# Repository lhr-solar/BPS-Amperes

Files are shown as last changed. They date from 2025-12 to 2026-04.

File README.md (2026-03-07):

# BPS-Amperes

### Board Specification
- Measures battery current using low-side shunt resistor.

### Confluence
- https://cloud.wikis.utexas.edu/wiki/spaces/LHRSOLAR/pages/172360934/Amperes+Board

### Building / Testing
- To build main firmware, cd into Firmware folder and run ``` make ``` to build main files. 
- To build tests, cd into Fimrware folder and run ``` make TEST=test_name ```, where ```test_name``` is the name of the test without the .c suffix.
- Run ``` make help ``` for specific instructions.

### Flashing
- Attach USB device using USBIPD and flash via UART (``` make flash-uart ```) or ST-Link (``` make flash ```).

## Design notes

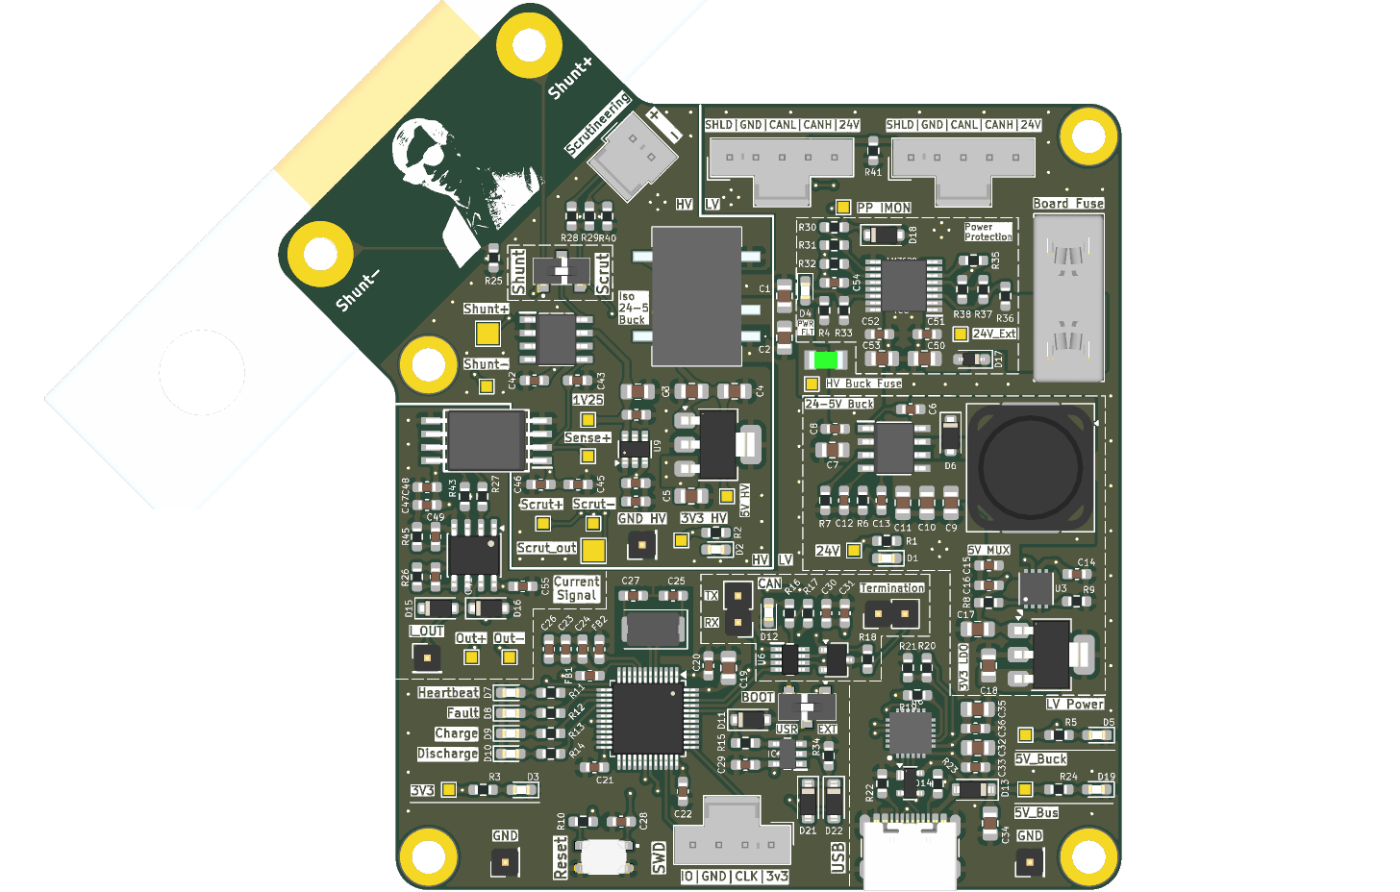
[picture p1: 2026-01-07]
Hardware/docs/render.png

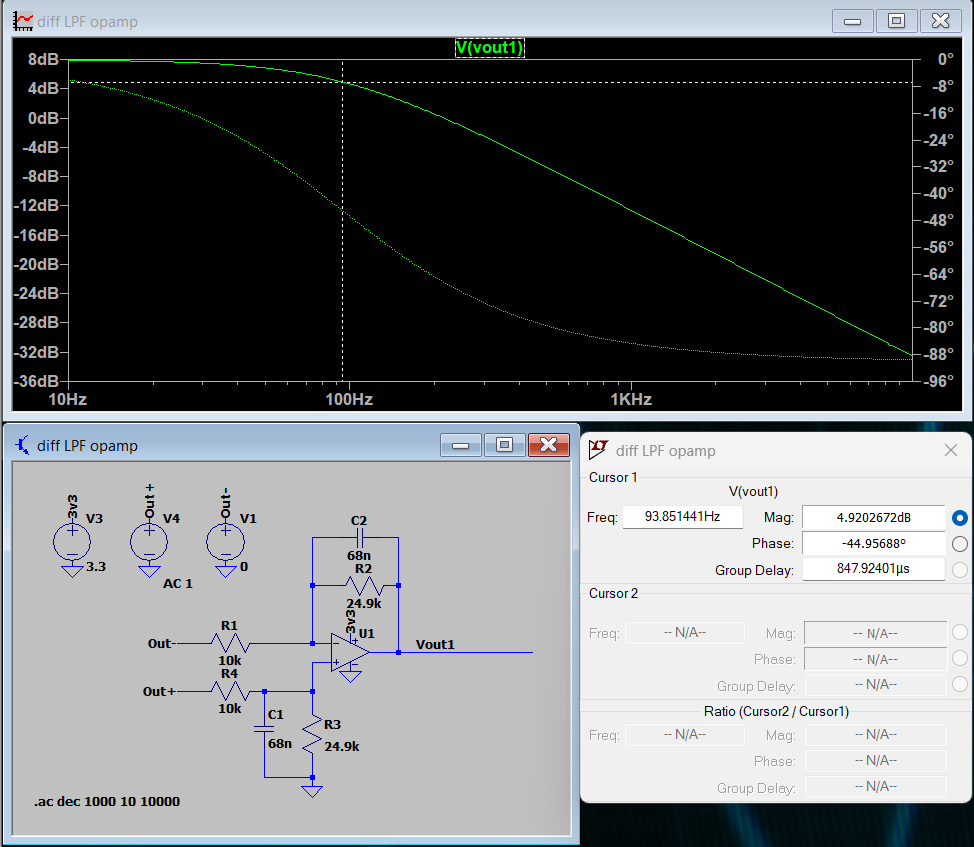
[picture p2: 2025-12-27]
Hardware/Amperes Design/RevB Low-Pass Filter.png

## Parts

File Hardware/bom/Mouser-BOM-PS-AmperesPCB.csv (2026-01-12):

Comment | Mouser P/N | Quantity | Designator
PTC Fuse | 576-1206L010/30WR | 1 | F1
3568 Fuse | 534-3568 | 1 | F2
INA241A4IDR | 595-INA241A4IDR | 1 | IC2
100uH | 994-MSS1246-104MLC | 1 | L1
WE 1769205341 | 710-1769205341 | 1 | PS1
SPDT Switch | 229-CJS-1200TA | 2 | SW2
CDSOT23-T24CAN | 652-CDSOT23-T24CAN | 1 | U7
4.3k 0603 Resistor | 71-CRCW0603-4.3K-E3 | 2 | R1,R4
WSBS8518L2500JTP3 | 71-WSBS8518L2500JTP3 | 1 | R39

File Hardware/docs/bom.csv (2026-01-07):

Reference | Value | Footprint | Qty | p/n
C1,C2,C19,C32,C35 | 4.7uF | Capacitor_SMD:C_0805_2012Metric_Pad1.18x1.45mm_HandSolder | 5
C3,C4,C5,C7,C9,C10,C11,C17,C18,C34,C39,C50,C53 | 10uF | Capacitor_SMD:C_0805_2012Metric_Pad1.18x1.45mm_HandSolder | 13
C6,C14,C15,C29,C33,C36,C37,C40,C42,C55 | 0.1uF | Capacitor_SMD:C_0603_1608Metric_Pad1.08x0.95mm_HandSolder | 10
C8,C16,C38,C46,C47,C51,C52 | 1uF | Capacitor_SMD:C_0603_1608Metric_Pad1.08x0.95mm_HandSolder | 7
C12 | 10nF | Capacitor_SMD:C_0603_1608Metric_Pad1.08x0.95mm_HandSolder | 1
C13 | 3.3nF | Capacitor_SMD:C_0603_1608Metric_Pad1.08x0.95mm_HandSolder | 1
C20,C21,C22,C23,C24,C26,C28,C30,C31,C45,C48,C54 | 100nF | Capacitor_SMD:C_0603_1608Metric_Pad1.08x0.95mm_HandSolder | 12
C25,C27 | 12p | Capacitor_SMD:C_0603_1608Metric_Pad1.08x0.95mm_HandSolder | 2
C41,C49 | 68nF | Capacitor_SMD:C_0603_1608Metric_Pad1.08x0.95mm_HandSolder | 2
C43 | 1nF | Capacitor_SMD:C_0603_1608Metric_Pad1.08x0.95mm_HandSolder | 1
D1,TP3 | 24V | LED_SMD:LED_0603_1608Metric_Pad1.05x0.95mm_HandSolder,TestPoint:TestPoint_Pad_1.0x1.0mm | 2
D2 | 3.3V HV | LED_SMD:LED_0603_1608Metric_Pad1.05x0.95mm_HandSolder | 1
D3 | 3.3V | LED_SMD:LED_0603_1608Metric_Pad1.05x0.95mm_HandSolder | 1
D4 | PFLT | LED_SMD:LED_0603_1608Metric_Pad1.05x0.95mm_HandSolder | 1
D5 | BUCK | LED_SMD:LED_0603_1608Metric_Pad1.05x0.95mm_HandSolder | 1
D6 | MBR230S1F | Diode_SMD:D_SOD-123F | 1
D7 | Heartbeat | LED_SMD:LED_0603_1608Metric_Pad1.05x0.95mm_HandSolder | 1
D8 | Fault | LED_SMD:LED_0603_1608Metric_Pad1.05x0.95mm_HandSolder | 1
D9 | Charge | LED_SMD:LED_0603_1608Metric_Pad1.05x0.95mm_HandSolder | 1
D10 | Discharge | LED_SMD:LED_0603_1608Metric_Pad1.05x0.95mm_HandSolder | 1
D11,D15,D16,D17,D18 | TVS | Diode_SMD:D_SOD-123F,Diode_SMD:D_SOD-323_HandSoldering | 5
D12 | CAN Status | LED_SMD:LED_0603_1608Metric_Pad1.05x0.95mm_HandSolder | 1
D13,D21,D22 | 1N5819HW | Diode_SMD:D_SOD-123 | 3
D14 | SP0503BAHT | Package_TO_SOT_SMD:SOT-143 | 1
D19 | VBUS | LED_SMD:LED_0603_1608Metric_Pad1.05x0.95mm_HandSolder | 1
F1 | Fuse | Parts:FUSC3216X125N | 1
F2 | 3568 | Parts:FUSE_3568 | 1
FB1,FB2 | FerriteBead | Capacitor_SMD:C_0603_1608Metric_Pad1.08x0.95mm_HandSolder | 2
H1 | M1 | MountingHole:MountingHole_3.2mm_M3_DIN965_Pad_TopBottom | 1
H2 | M3 | MountingHole:MountingHole_3.2mm_M3_DIN965_Pad_TopBottom | 1
H3 | M2 | MountingHole:MountingHole_3.2mm_M3_DIN965_Pad_TopBottom | 1
H4 | M4 | MountingHole:MountingHole_3.2mm_M3_DIN965_Pad_TopBottom | 1
IC1 | SN74AHC1G32DBVR | Parts:SN74AHC1G32DBVR | 1
IC2 | INA241A4IDR | Parts:INA241A5IDR | 1
IC3 | AMC1350DWVR | Parts:AMC1350DWVR | 1
IC5 | LM76202QPWPRQ1 | UTSVT_Power:LM76202QPWPRQ1 | 1
J1 | PeripheralCAN | UTSVT_Connectors:Molex_Nano-Fit_105309-xx04_1x04_P2.50mm_Vertical | 1
J3 | SWD | Connector_Molex:Molex_Nano-Fit_105309-xx04_1x04_P2.50mm_Vertical | 1
J4 | Conn_01x02_Pin | Connector_PinHeader_2.54mm:PinHeader_1x02_P2.54mm_Vertical | 1
J5 | USB4105-GF-A | UTSVT_Connectors:USB_C_Receptacle_GCT_USB4105-xx-A_16P_TopMnt_Horizontal | 1
J6 | Scrut Conn | Connector_Molex:Molex_Nano-Fit_105309-xx02_1x02_P2.50mm_Vertical | 1
J7,J8 | Nanofit 1x05 | Connector_Molex:Molex_Nano-Fit_105309-xx05_1x05_P2.50mm_Vertical | 2
JP1 | Termination | Connector_PinHeader_2.54mm:PinHeader_1x02_P2.54mm_Vertical | 1
L1 | 100uH | Inductor_SMD:L_Coilcraft_MSS1246-XXX | 1
LOGO1 | logo placeholder | UTSVT_Logos:LHRs_LOGO | 1
LOGO2 | Dr. Hallock | UTSVT_Logos:Hallock_Image_Tiny | 1
PS1 | 1769205341 | Parts:WE_1769205341 | 1
R1,R4 | 4.3k | Resistor_SMD:R_0603_1608Metric_Pad0.98x0.95mm_HandSolder | 2
R2,R3,R11,R12,R13,R14,R16,R18 | 120 | Resistor_SMD:R_0603_1608Metric_Pad0.98x0.95mm_HandSolder | 8
R5,R19,R24 | 1k | Resistor_SMD:R_0603_1608Metric_Pad0.98x0.95mm_HandSolder | 3
R6 | 16k | Resistor_SMD:R_0603_1608Metric_Pad0.98x0.95mm_HandSolder | 1
R7 | ROSC | Resistor_SMD:R_0603_1608Metric_Pad0.98x0.95mm_HandSolder | 1
R8,R10,R15,R17,R27,R32,R33,R34,R43 | 10k | Resistor_SMD:R_0603_1608Metric_Pad0.98x0.95mm_HandSolder | 9
R9 | 332 | Resistor_SMD:R_0603_1608Metric_Pad0.98x0.95mm_HandSolder | 1
R20 | 22k | Resistor_SMD:R_0603_1608Metric_Pad0.98x0.95mm_HandSolder | 1
R21,R28 | 47k | Resistor_SMD:R_0603_1608Metric_Pad0.98x0.95mm_HandSolder | 2
R22,R23 | 5.1k | Resistor_SMD:R_0603_1608Metric_Pad0.98x0.95mm_HandSolder | 2
R25,R40,R41 | 0 | Resistor_SMD:R_0603_1608Metric_Pad0.98x0.95mm_HandSolder | 3
R26,R45 | 24.9k | Resistor_SMD:R_0603_1608Metric_Pad0.98x0.95mm_HandSolder | 2
R29 | 50 | Resistor_SMD:R_0603_1608Metric_Pad0.98x0.95mm_HandSolder | 1
R30 | 100k | Resistor_SMD:R_0603_1608Metric_Pad0.98x0.95mm_HandSolder | 1
R31 | 19k | Resistor_SMD:R_0603_1608Metric_Pad0.98x0.95mm_HandSolder | 1
R35 | 402k | Resistor_SMD:R_0603_1608Metric_Pad0.98x0.95mm_HandSolder | 1
R36 | 45.3k | Resistor_SMD:R_0603_1608Metric_Pad0.98x0.95mm_HandSolder | 1
R37 | 590 | Resistor_SMD:R_0603_1608Metric_Pad0.98x0.95mm_HandSolder | 1
R38 | 2.1k | Resistor_SMD:R_0603_1608Metric_Pad0.98x0.95mm_HandSolder | 1
R39 | WSBS8518L2500JTP3 | Parts:WSBS8518L2500JKM4 | 1
SW1 | RST | Parts:SW_TL3365AF180QG | 1
SW2 | BOOT | Parts:SW_CJS-1200TA | 1
SW4 | Scrut Select | Parts:SW_CJS-1200TA | 1
TP1 | I_OUT | Connector_PinHeader_2.54mm:PinHeader_1x01_P2.54mm_Vertical | 1
TP2 | 24V_Ext | TestPoint:TestPoint_Pad_1.0x1.0mm | 1
TP4 | 3V3_HV | TestPoint:TestPoint_Pad_1.0x1.0mm | 1
TP5 | 3V3 | TestPoint:TestPoint_Pad_1.0x1.0mm | 1
TP6 | 5V_BK | TestPoint:TestPoint_Pad_1.0x1.0mm | 1
TP7 | 5V_USB | TestPoint:TestPoint_Pad_1.0x1.0mm | 1
TP8,TP15 | GND | Connector_PinHeader_2.54mm:PinHeader_1x01_P2.54mm_Vertical | 2
TP9 | GND HV | Connector_PinHeader_2.54mm:PinHeader_1x01_P2.54mm_Vertical | 1
TP10 | SHUNT+ | TestPoint:TestPoint_Pad_2.0x2.0mm | 1
TP11 | SHUNT- | TestPoint:TestPoint_Pad_1.0x1.0mm | 1
TP12 | V_In+ | TestPoint:TestPoint_Pad_1.0x1.0mm | 1
TP13 | V_Out+ | TestPoint:TestPoint_Pad_2.0x2.0mm | 1
TP14 | V_In- | TestPoint:TestPoint_Pad_1.0x1.0mm | 1
TP16 | 1V25 | TestPoint:TestPoint_Pad_1.0x1.0mm | 1
TP17 | Sense+ | TestPoint:TestPoint_Pad_1.0x1.0mm | 1
TP18 | Out+ | TestPoint:TestPoint_Pad_1.0x1.0mm | 1
TP19 | IMON | TestPoint:TestPoint_Pad_1.0x1.0mm | 1
TP20 | Out- | TestPoint:TestPoint_Pad_1.0x1.0mm | 1
TP21 | 5V_HV | TestPoint:TestPoint_Pad_1.0x1.0mm | 1
TP22 | 24V_HV | TestPoint:TestPoint_Pad_1.0x1.0mm | 1
U1,U4 | LT1963AEST-3.3#TRPBF | Package_TO_SOT_SMD:SOT-223-3_TabPin2 | 2
U2 | TPS5405DR | UTSVT_Power:TPS5405DR | 1
U3 | TPS2115ADRBR | Package_SON:VSON-8-1EP_3x3mm_P0.65mm_EP1.65x2.4mm | 1
U5 | STM32L431CBTx | Package_QFP:LQFP-48_7x7mm_P0.5mm | 1
U6 | TCAN337 | UTSVT_ICs:TCAN337DCNR | 1
U7 | CDSOT23-T24CAN | UTSVT_ICs:CDSOT23-T24CAN | 1
U8 | CP2102N-A02-GQFN24 | UTSVT_ICs:CP2102N-A02-GQFN24 | 1
U9 | REF35125QDBVR | Package_TO_SOT_SMD:SOT-23-6 | 1
U10 | TLV9002QDRQ1 | Package_SO:SOIC-8_3.9x4.9mm_P1.27mm | 1
Y1 | 8M | Crystal:Crystal_SMD_Abracon_ABM3-2Pin_5.0x3.2mm | 1

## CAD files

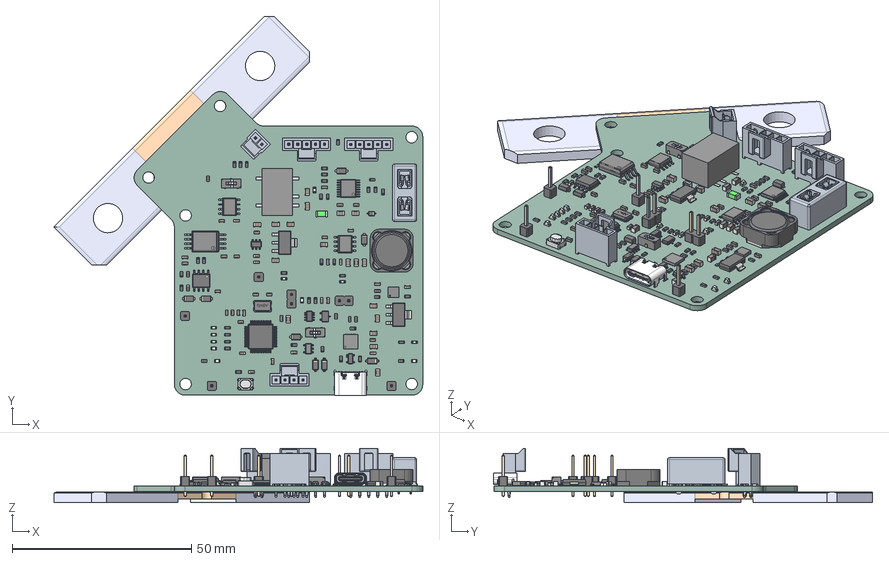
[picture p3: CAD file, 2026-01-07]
Hardware/Amperes Design/PS-AmperesPCB.step
102.8 x 105.7 x 15.1 mm
C_0603_1608Metric x 38
R_0603_1608Metric x 42
D_SOD-123F x 5
PinHeader_1x02_P2.54mm_Vertical x 2
kicad_embedded_9406EA57197DC5EF7108E35EAA086FA7
PinHeader_1x01_P2.54mm_Vertical x 4
TL3365AF180QG--3DModel-STEP-520916
LED_0603_1608Metric x 11
C_0805_2012Metric x 18
USB4215-03-A_PART1
USB4215-03-A_PART2
BODY-SO x 3
LEAD-SO x 8
BODY-SOT
LEAD-SOT x 5
LEAD-DUMMY
LEAD-D0008A x 16
F3568-1
3557_rev.C x 2
BODY-SOIC
LEAD-DWV0008A x 8
ThermalPin
PinsArrayLR
PinsArrayTB
kicad_embedded_DC8F7DF302591227B9F71E251B6FE682 x 2
SOT-143
SOT-23-6
D_SOD-123 x 3
D_SOD-323
SOIC-8_3.9x4.9mm_P1.27mm
LQFP-48_7x7mm_P0.5mm
Pins
SOT-223 x 2
term1
term2
L_Coilcraft_MSS1246-XXX
BODY-TSSOP
LEAD-TSSOP x 16
PIN1
DAP
kicad_embedded_92F559AF6EAD82363E65197C234718B9
SOT-23W
kicad_embedded_65BE167E2F18E41A0258338831D6EB54
PS-AmperesPCB_PCB

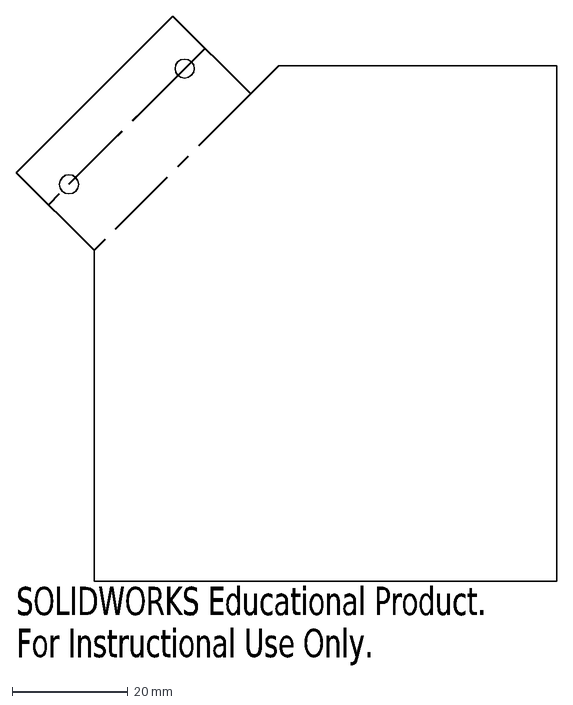
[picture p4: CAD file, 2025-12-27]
Hardware/Amperes Design/amperesmax.DXF
SOLIDWORKS Educational Product.
For Instructional Use Only.

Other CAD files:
Hardware/docs/board.step

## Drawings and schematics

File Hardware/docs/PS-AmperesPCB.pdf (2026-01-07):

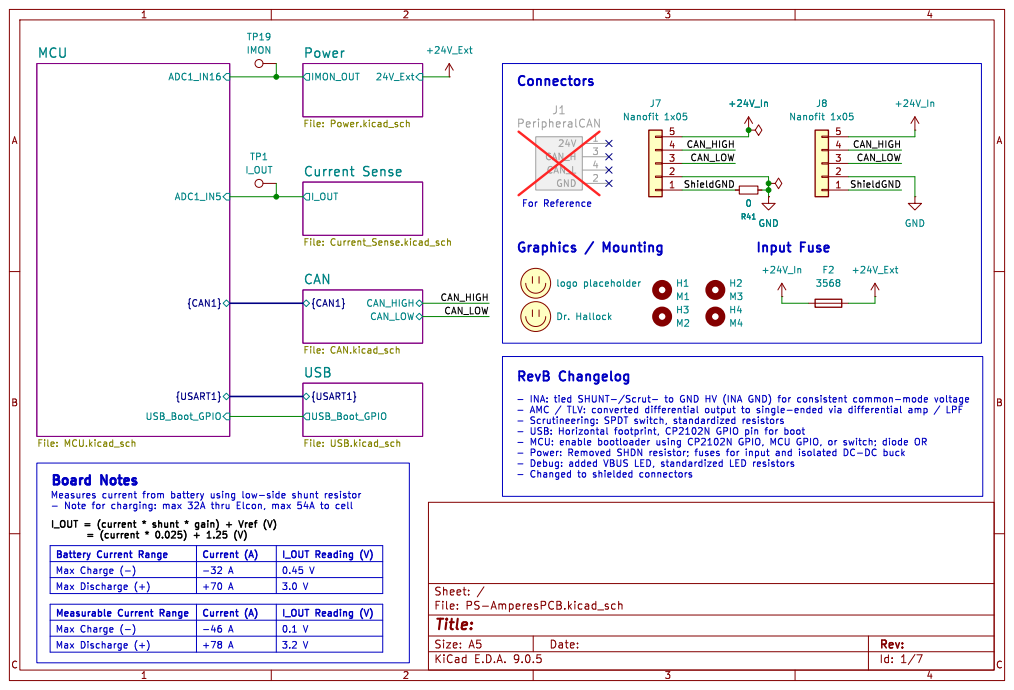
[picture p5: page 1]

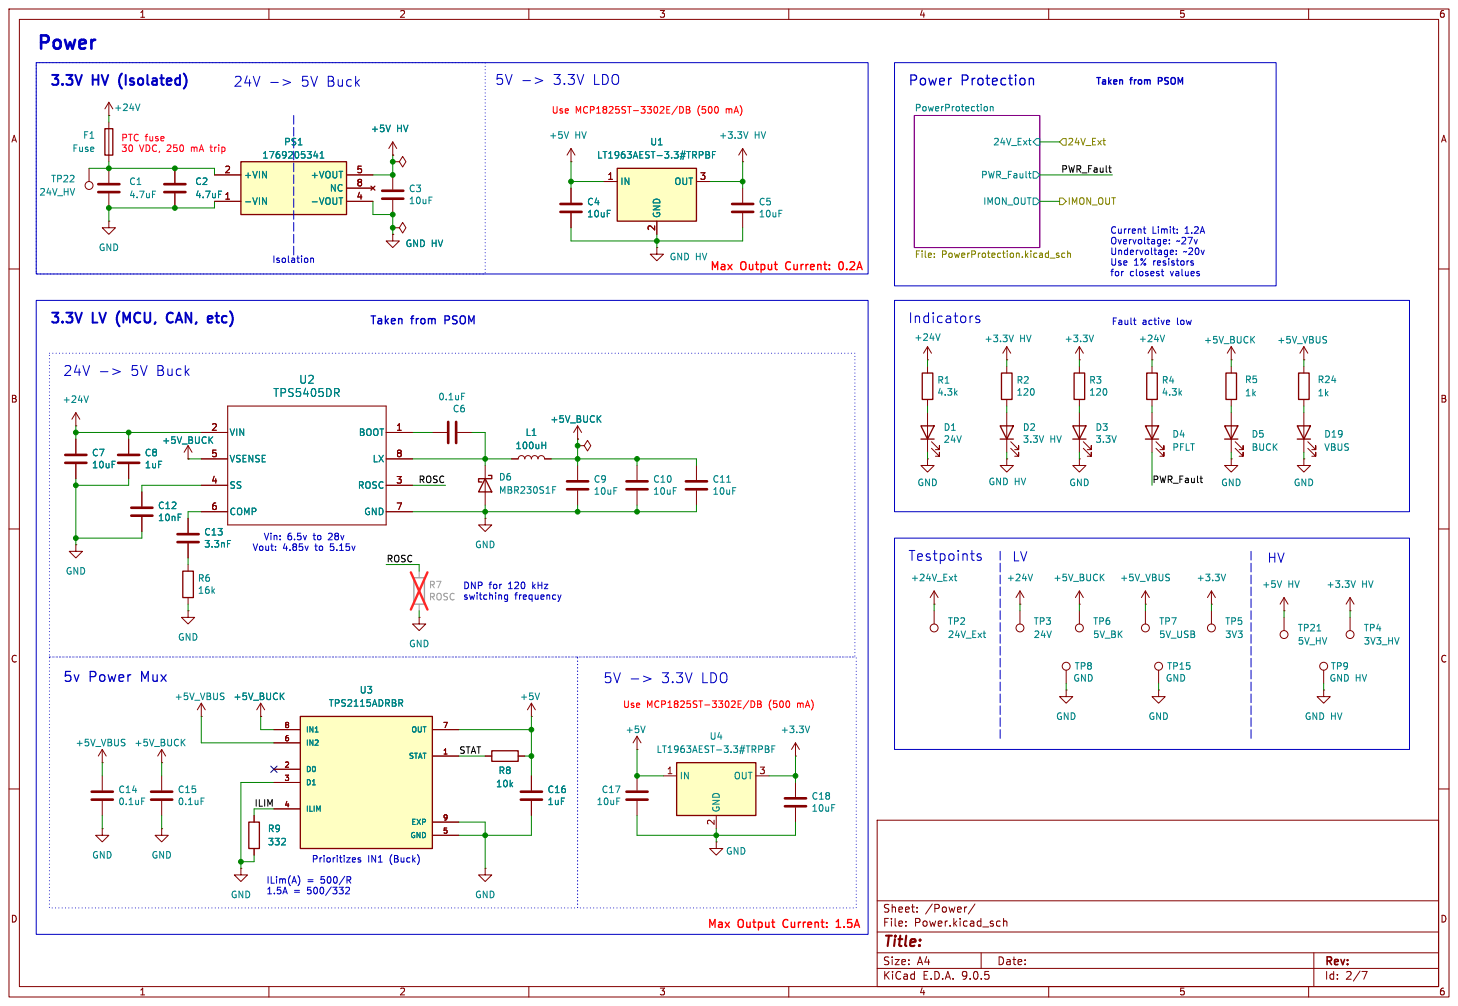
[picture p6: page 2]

Isolation 3.3V LV (MCU, CAN, etc) C2

for closest values Fault active low Max Output Current: 1.5A

Id: 2/7 Title: File: Power.kicad_sch Sheet: /Power/

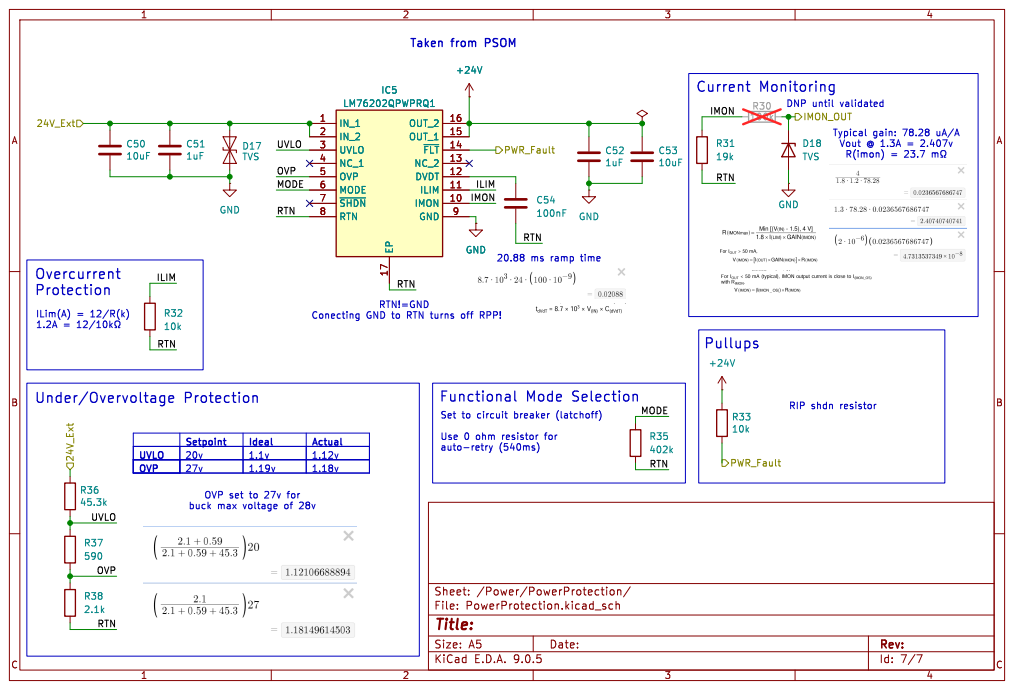
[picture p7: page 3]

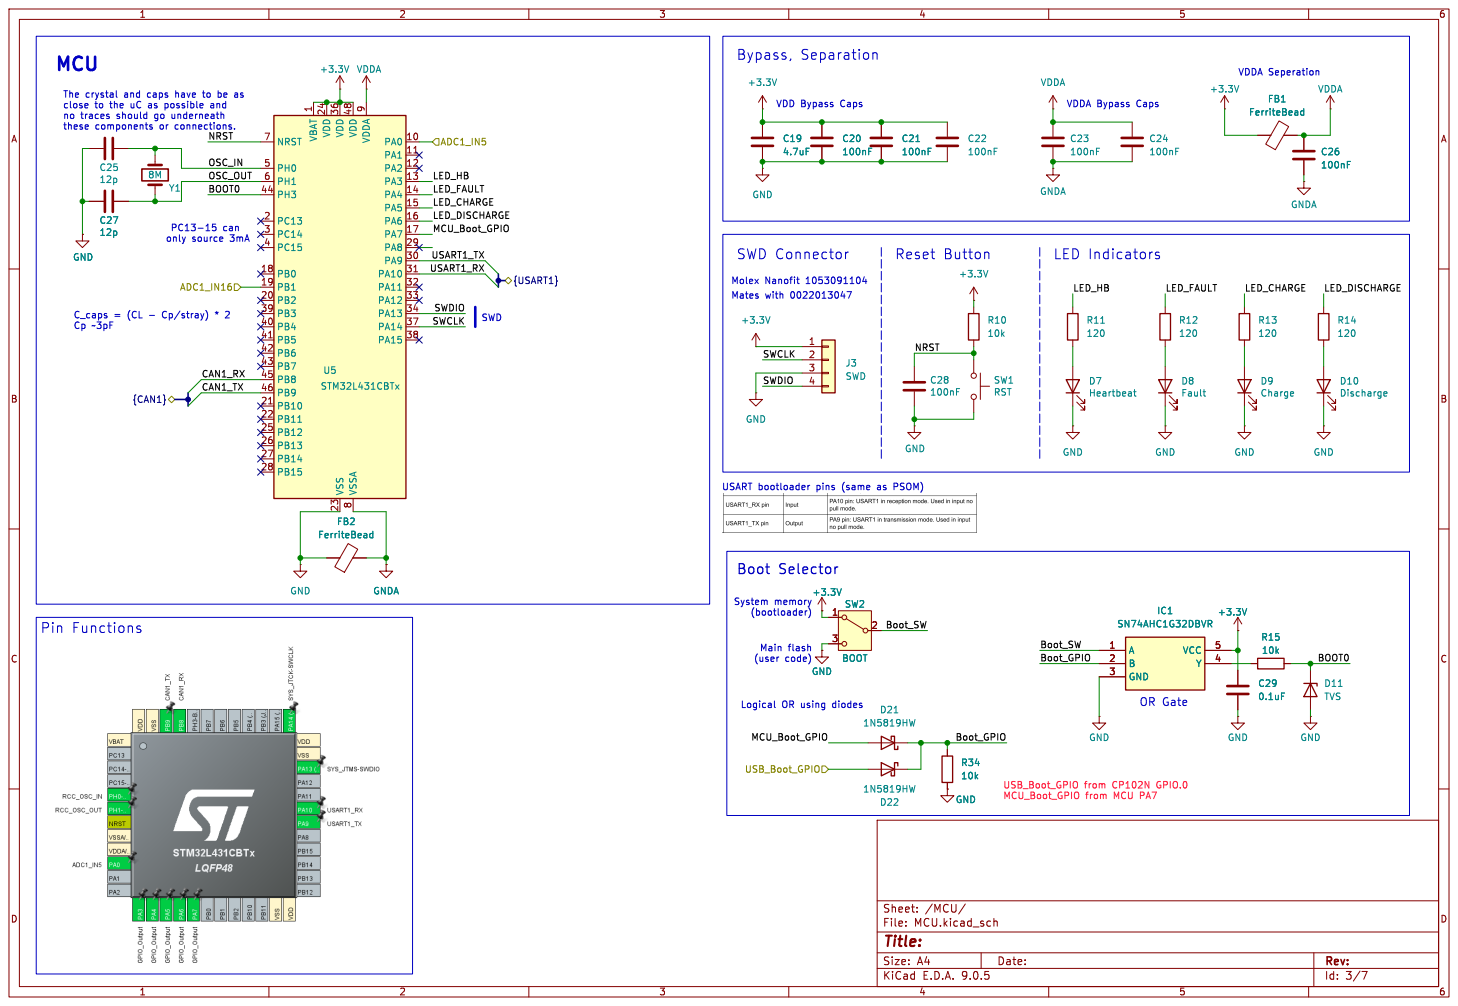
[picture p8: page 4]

(user code) Mates with 0022013047 MCU

VDDA Seperation VDDA Bypass Caps
FB1 FerriteBead C23

The crystal and caps have to be as
no traces should go underneath

1 VDD 24 VDD 36 VSS 23 VDD 48 VSSA

Id: 3/7 Title: File: MCU.kicad_sch Sheet: /MCU/ GND

OR Gate Main flash

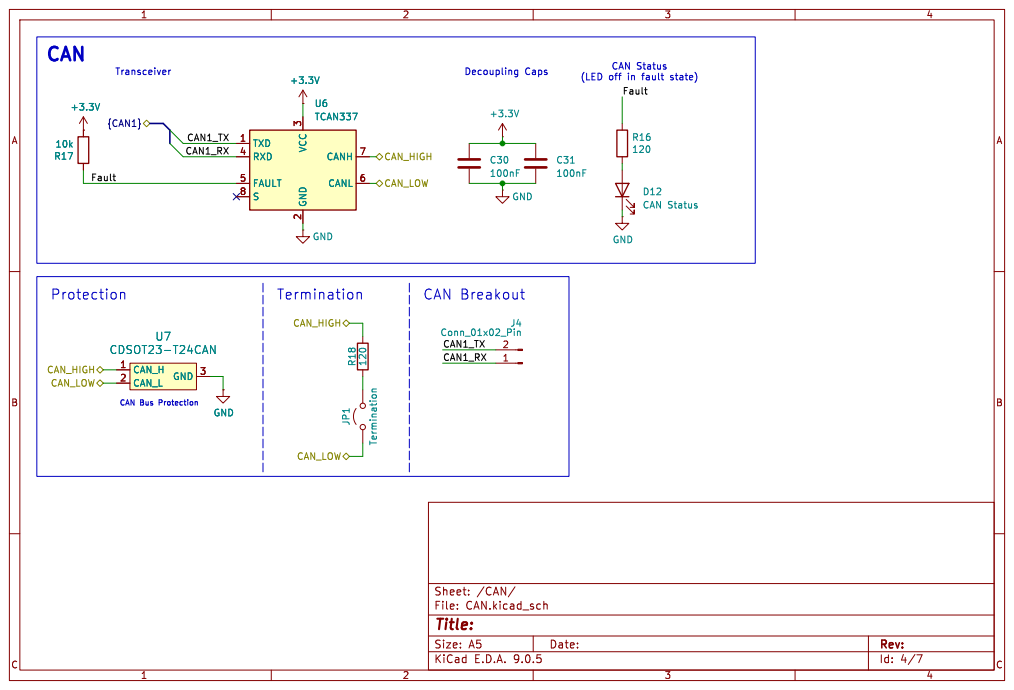
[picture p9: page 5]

(LED off in fault state)

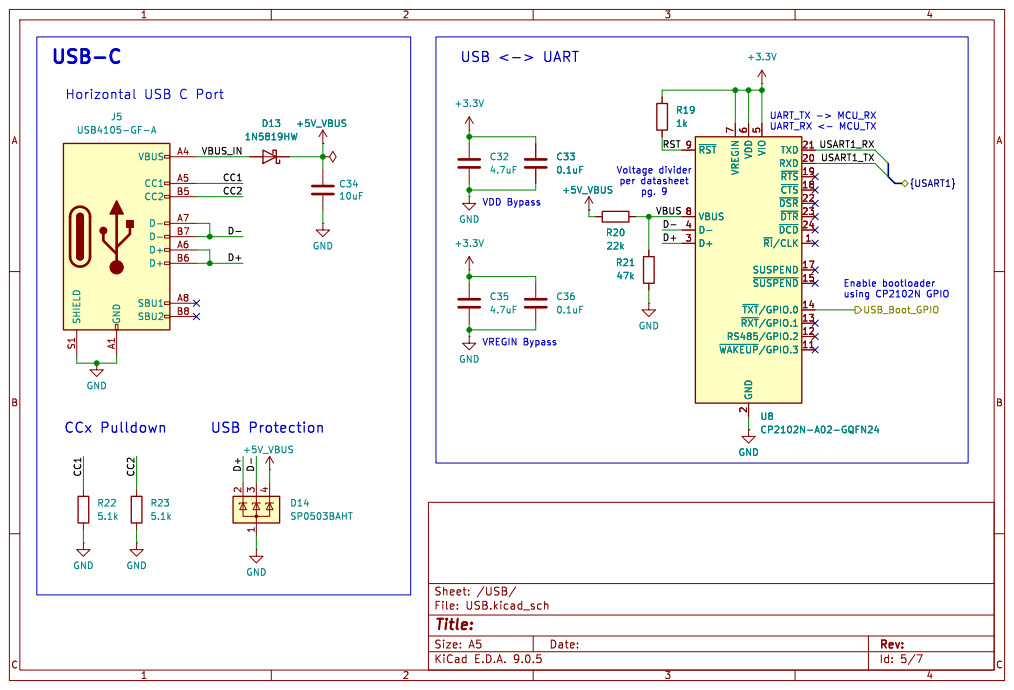
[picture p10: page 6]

USB-C
Voltage divider per datasheet pg. 9 CCx Pulldown

5 TXD 21 RXD 20 ~{RTS} 19 ~{CTS} 18 ~{DSR} 22 ~{DTR} 23 ~{DCD} 24 ~{RI}/CLK1 SUSPEND 17 ~{SUSPEND}15 ~{TXT}/GPIO.014 ~{RXT}/GPIO.113 RS485/GPIO.2 12 ~{WAKEUP}/GPIO.311 U8 CP2102N-A02-GQFN24 +5V_VBUS

5 TXD 21 RXD 20 ~{RTS} 19 ~{CTS} 18 ~{DSR} 22 ~{DTR} 23 ~{DCD} 24 ~{RI}/CLK1 SUSPEND 17 ~{SUSPEND}15 ~{TXT}/GPIO.014 ~{RXT}/GPIO.113 RS485/GPIO.2 12 ~{WAKEUP}/GPIO.311 GND

Id: 5/7 Title: File: USB.kicad_sch Sheet: /USB/

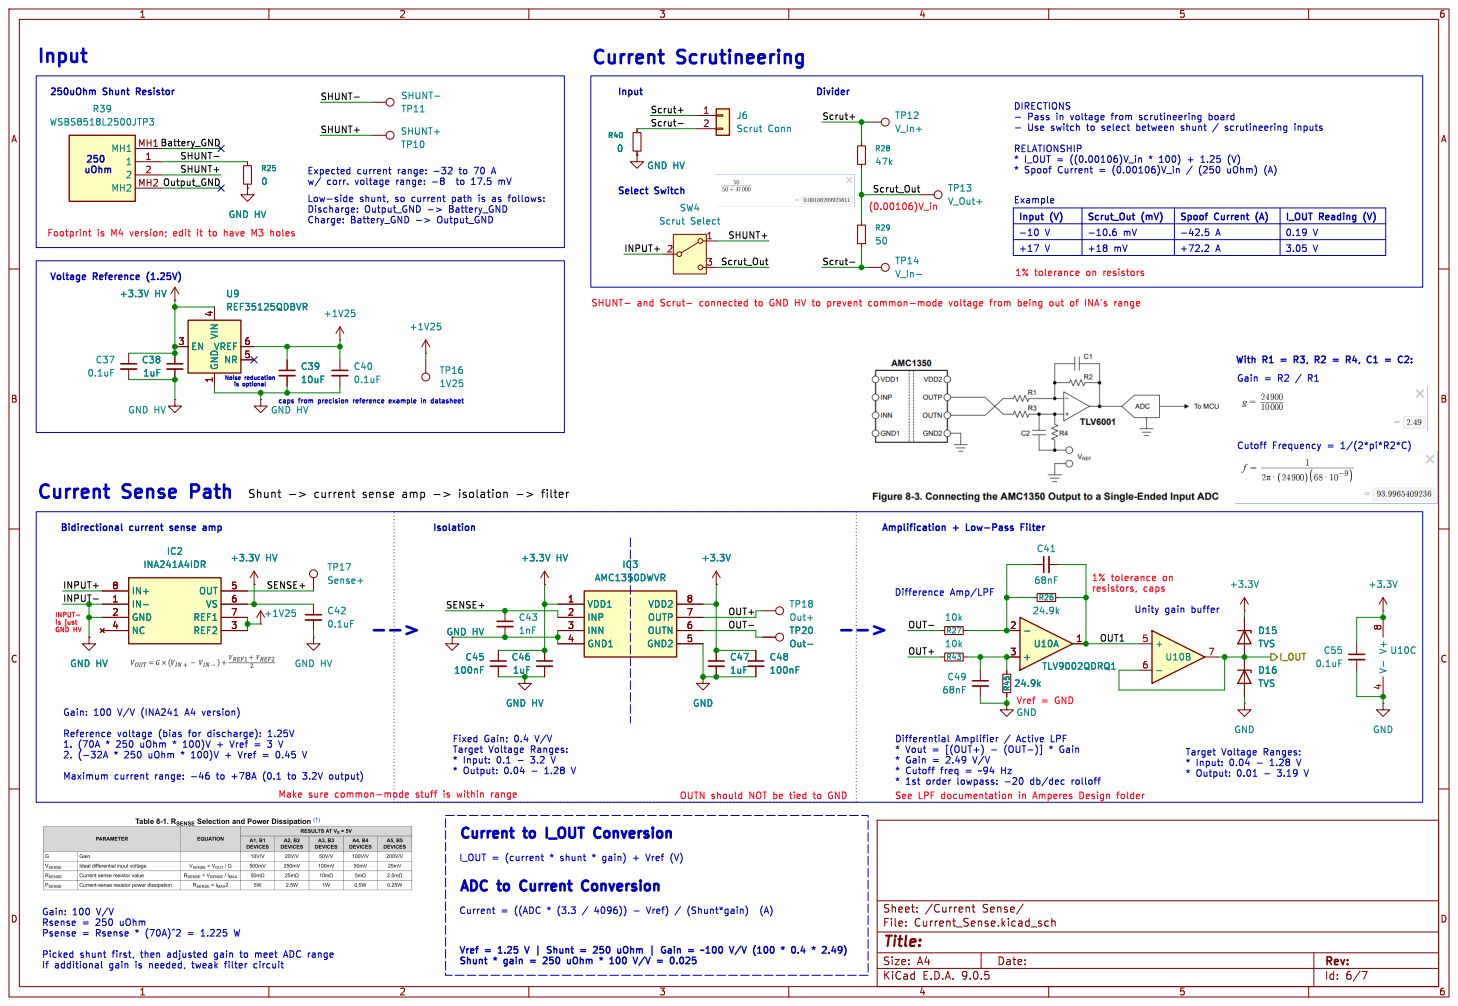
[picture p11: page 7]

250uOhm Shunt Resistor Voltage Reference (1.25V) 250 uOhm

Target Voltage Ranges: * Input: 0.1 - 3.2 V

ADC to Current Conversion

Vref = 1.25 V | Shunt = 250 uOhm | Gain = ~100 V/V (100 * 0.4 * 2.49) Shunt * gain = 250 uOhm * 100 V/V = 0.025

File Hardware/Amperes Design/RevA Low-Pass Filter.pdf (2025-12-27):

## Filter Design Report

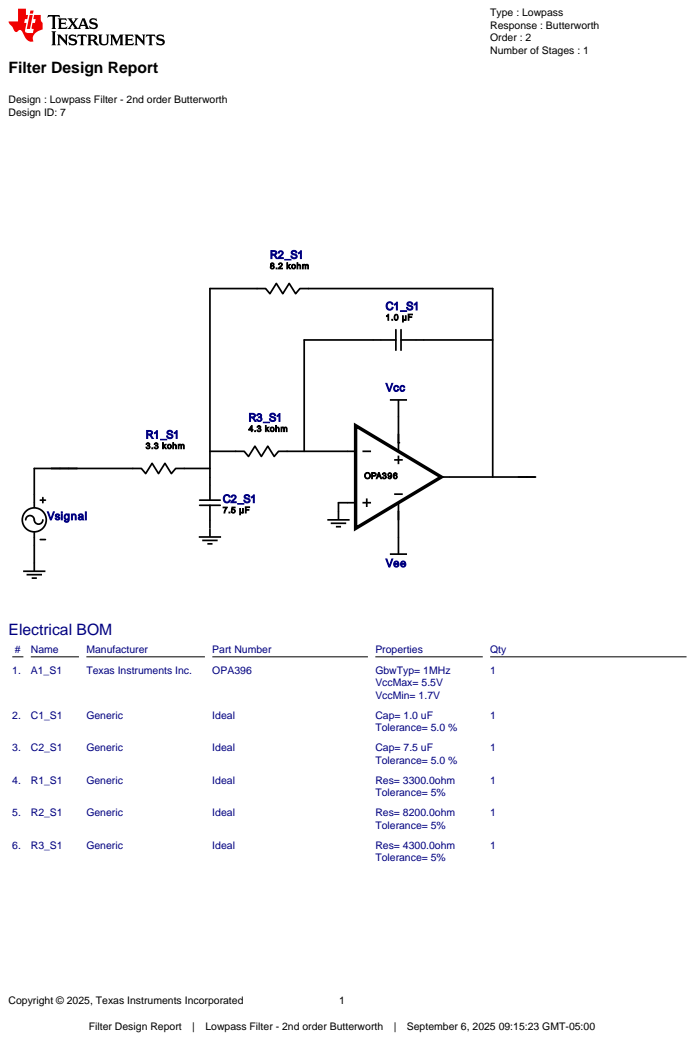
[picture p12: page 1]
Copyright © 2025, Texas Instruments Incorporated; Vsignal; OPA396; R1_S1 3.3 kohm; R2_S1 8.2 kohm; R3_S1 4.3 kohm; Vcc; Vee; Electrical BOM; # Name; Manufacturer; Part Number; Properties; Qty; Texas Instruments Inc.; GbwTyp= 1MHz; VccMax= 5.5V VccMin= 1.7V; Generic; Ideal; Cap= 1.0 uF; Tolerance= 5.0 %; Cap= 7.5 uF; Res= 3300.0ohm; Tolerance= 5%; Res= 8200.0ohm; Res= 4300.0ohm

Type : Lowpass
Response : Butterworth
Order : 2
Number of Stages : 1

Design : Lowpass Filter - 2nd order Butterworth
Design ID: 7

Filter Design Report | Lowpass Filter - 2nd order Butterworth | September 6, 2025 09:15:23 GMT-05:00

## Sensitivity Analysis

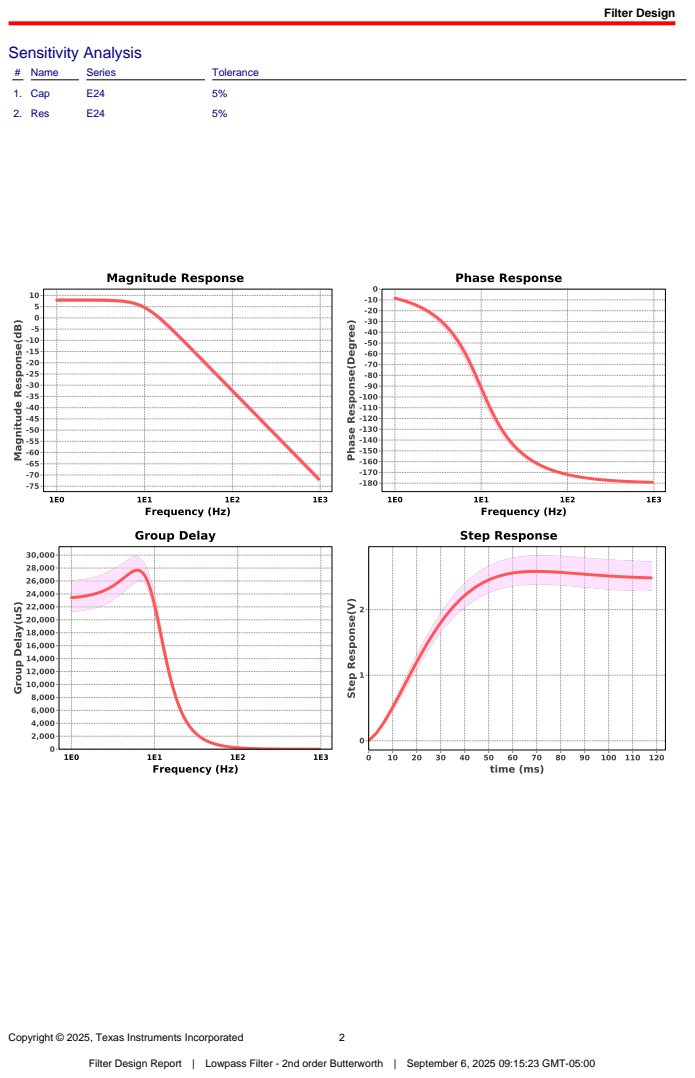
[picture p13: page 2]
Filter Design; # Name; Series; Tolerance; 1. Cap; 2. Res

## Design Inputs

# | Name | Value | Description

1. FilterType | lowpass
2. FilterResponse | Butterworth
3. FilterOrder | 2.0
4. FilterTopology | Multiple Feedback
5. NumberOfStages | 1.0
6. PassbandFrequency | 10.0
7. StopbandAttenuation | -40.001
8. StopbandFrequency | 100.0
9. Gain | 2.5
10. SingleSupply | 3.3 | Power supply(s) to active chips
11. ResistorTolerance | E24 | Resistor series - 5% Passive resistor tolerance
12. CapacitorTolerance | E24 | Capacitor series - 5% Passive capacitor tolerance

## Design Assistance

1. OPA396 Product Folder : http://www.ti.com/product/OPA396 : contains the data sheet and other resources.

# Filter Stage :1

Cutoff Frequency | 9.787 Hz
Min GBW Reqd | 1.768 kHz
Stage Gain | 2.485 V/V
Stage Q | 701.403 m
Stage Topology | Multiple Feedback
| R2_S1 8.2 kohm

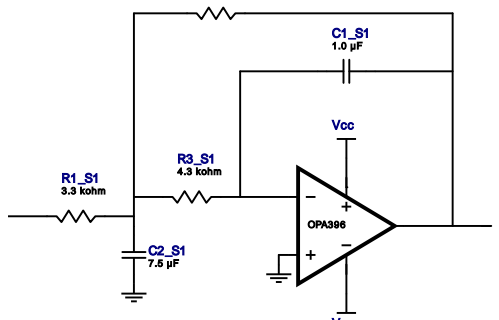
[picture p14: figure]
OPA396; R1_S1 3.3 kohm; R3_S1 4.3 kohm; Vcc

Vee

## Electrical BOM

# Name | Manufacturer | Part Number | Properties | Qty

1. A1_S1 | Texas Instruments Inc. | OPA396 | GbwTyp= 1MHz VccMax= 5.5V VccMin= 1.7V | 1
2. C1_S1 | Generic | Ideal | Cap= 1.0 uF Tolerance= 5.0 %

1

3. C2_S1 | Generic | Ideal | Cap= 7.5 uF Tolerance= 5.0 %

1

4. R1_S1 | Generic | Ideal | Res= 3300.0ohm Tolerance= 5%

1

5. R2_S1 | Generic | Ideal | Res= 8200.0ohm Tolerance= 5%

1

6. R3_S1 | Generic | Ideal | Res= 4300.0ohm Tolerance= 5%

1

Important Notice and Disclaimer

TI provides technical and reliability data (including datasheets), design resources (including reference designs), application or other design advice, web tools, safety information, and other resources AS IS and with all faults, and disclaims all warranties. These resources are intended for skilled developers designing with TI products. You are solely responsible for (1) selecting the appropriate TI products for your application, (2) designing, validating and testing your application, and (3) ensuring your application meets applicable standards, and any other safety, security, or other requirements.

These resources are subject to change without notice. TI grants you permission to use these resources only for development of an application that uses the TI products described in the resource. Other reproduction and display of these resources is prohibited. No license is granted to any other TI intellectual property right or to any third party intellectual property right. TI disclaims responsibility for, and you will fully indemnify TI and its representatives against, any claims, damages, costs, losses, and liabilities arising out of your use of these resources.

Providing these resources does not expand or otherwise alter TI's applicable Terms of Sale or other applicable terms available either on ti.com or provided in conjunction with TI products.

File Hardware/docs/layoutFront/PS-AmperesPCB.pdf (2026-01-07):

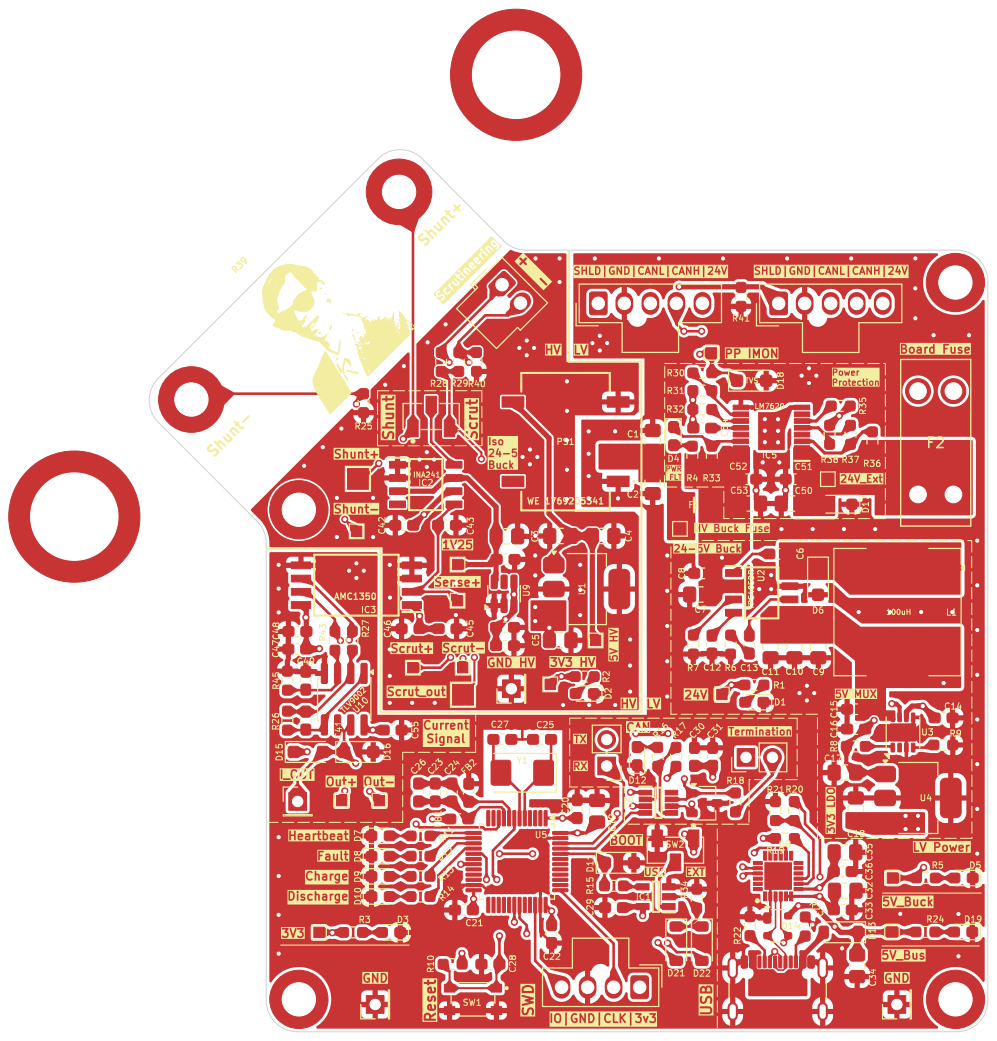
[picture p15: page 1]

Id: 1/1 Title: File: PS-AmperesPCB.kicad_pcb Sheet:

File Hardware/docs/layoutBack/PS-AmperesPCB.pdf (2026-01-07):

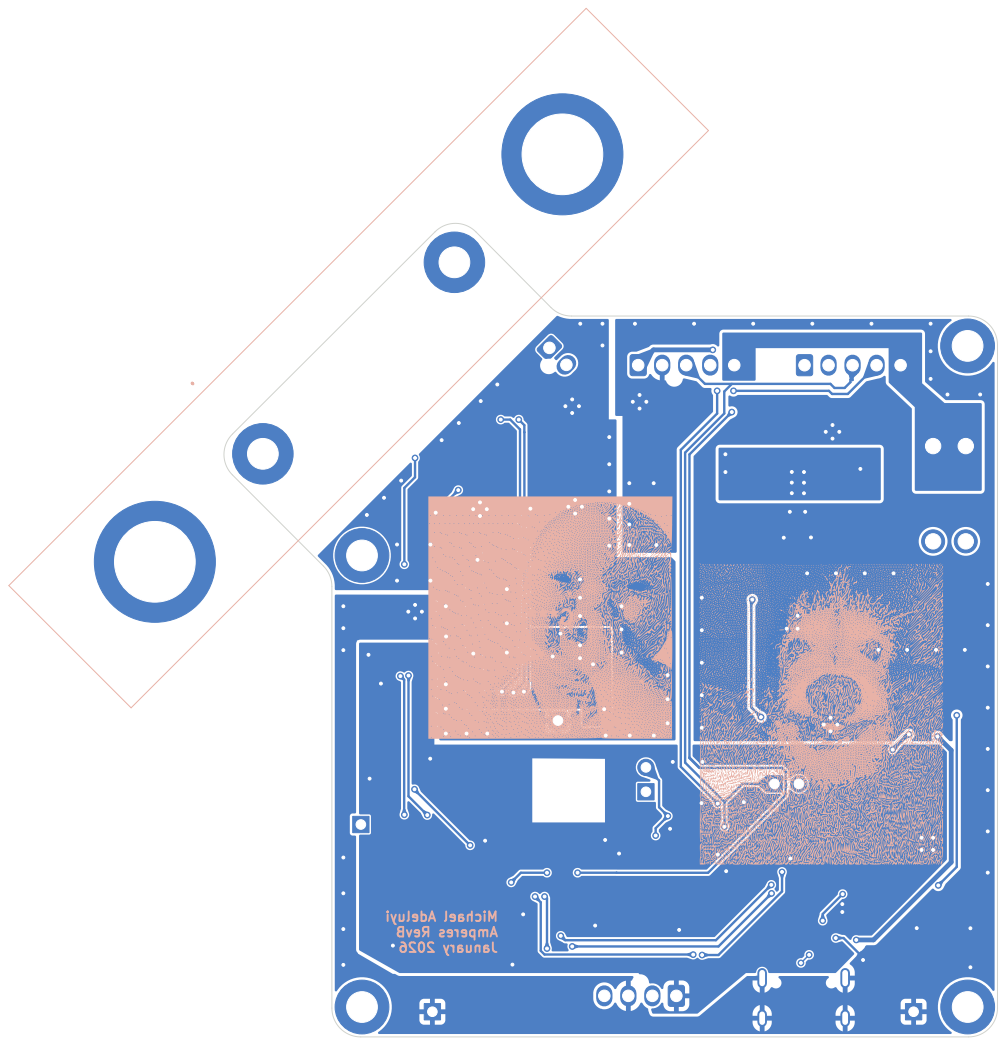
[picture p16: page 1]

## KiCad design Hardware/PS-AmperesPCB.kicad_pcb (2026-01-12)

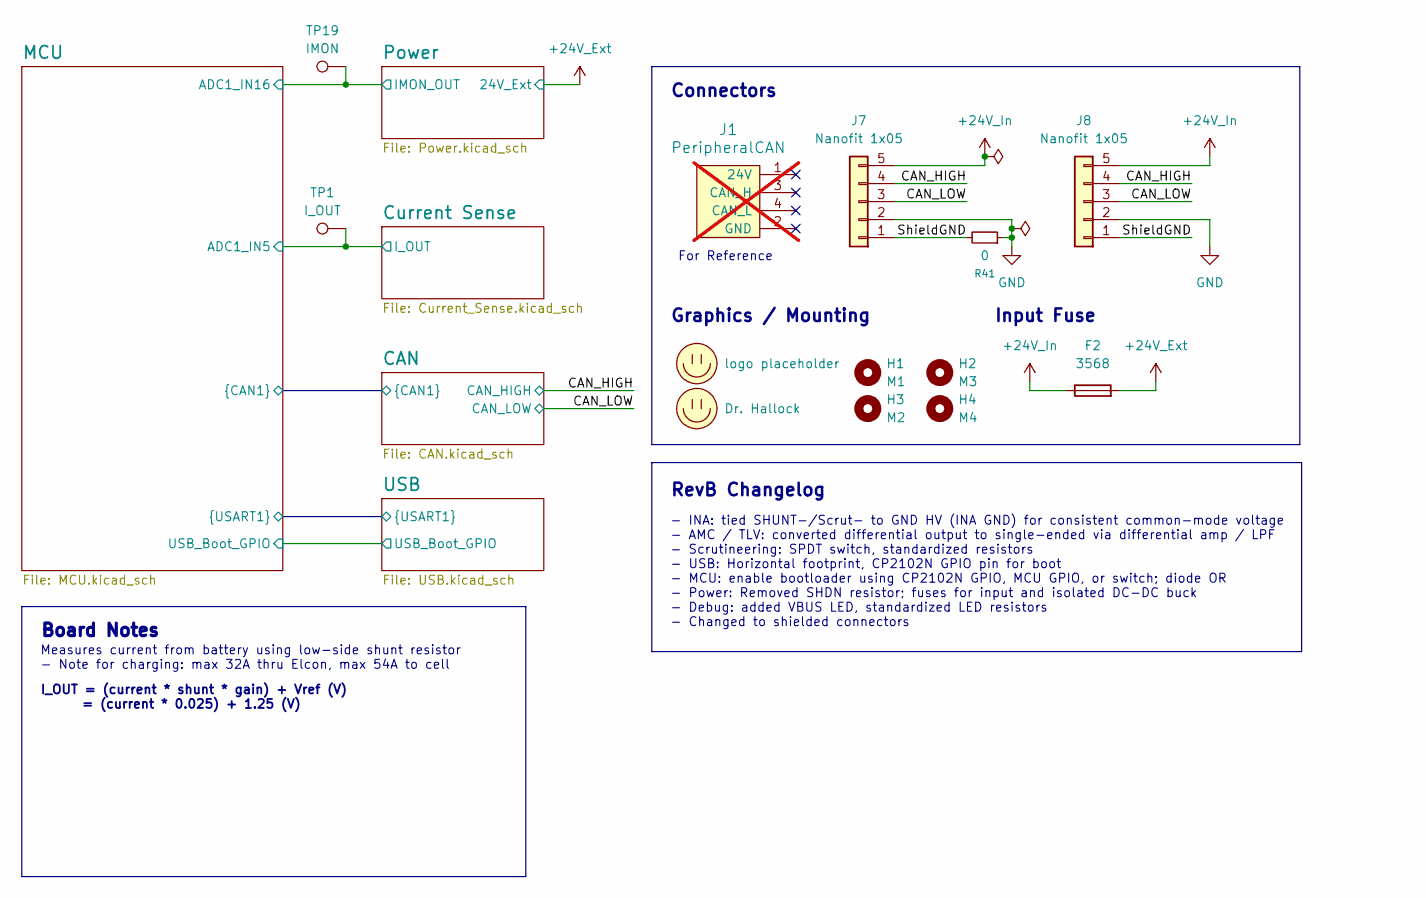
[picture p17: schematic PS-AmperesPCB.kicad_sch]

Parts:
F2: 3568; FUSE_3568
H1: M1; MountingHole_3.2mm_M3_DIN965_Pad_TopBottom
H2: M3; MountingHole_3.2mm_M3_DIN965_Pad_TopBottom
H3: M2; MountingHole_3.2mm_M3_DIN965_Pad_TopBottom
H4: M4; MountingHole_3.2mm_M3_DIN965_Pad_TopBottom
J1: PeripheralCAN; Molex_Nano-Fit_105309-xx04_1x04_P2.50mm_Vertical; not fitted
J7, J8: Nanofit 1x05; Molex_Nano-Fit_105309-xx05_1x05_P2.50mm_Vertical
LOGO1: logo placeholder; LHRs_LOGO
LOGO2: Dr. Hallock; Hallock_Image_Tiny
R41: 0; R_0603_1608Metric_Pad0.98x0.95mm_HandSolder
TP1: I_OUT; PinHeader_1x01_P2.54mm_Vertical
TP19: IMON; TestPoint_Pad_1.0x1.0mm

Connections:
+24V_Ext: F2.2; also elsewhere on the board
+24V_In: F2.1, J7.5, J8.5
/CAN_HIGH: J7.4, J8.4; also elsewhere on the board
/CAN_LOW: J7.3, J8.3; also elsewhere on the board
/Current Sense/I_OUT: TP1.1; also elsewhere on the board
/MCU/ADC1_IN16: TP19.1; also elsewhere on the board
/ShieldGND: J7.1, J8.1, R41.2
GND: J7.2, J8.2, R41.1; also elsewhere on the board

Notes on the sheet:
Board Notes
I_OUT = (current * shunt * gain) + Vref (V) = (current * 0.025) + 1.25 (V)
Graphics / Mounting
RevB Changelog
- INA: tied SHUNT-/Scrut- to GND HV (INA GND) for consistent common-mode voltage - AMC / TLV: converted differential output to single-ended via differential amp / LPF - Scrutineering: SPDT switch, standardized resistors - USB: Horizontal footprint, CP2102N GPIO pin for boot - MCU: enable bootloader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
Measures current from battery using low-side shunt resistor - Note for charging: max 32A thru Elcon, max 54A to cell
Connectors
For Reference
Input Fuse

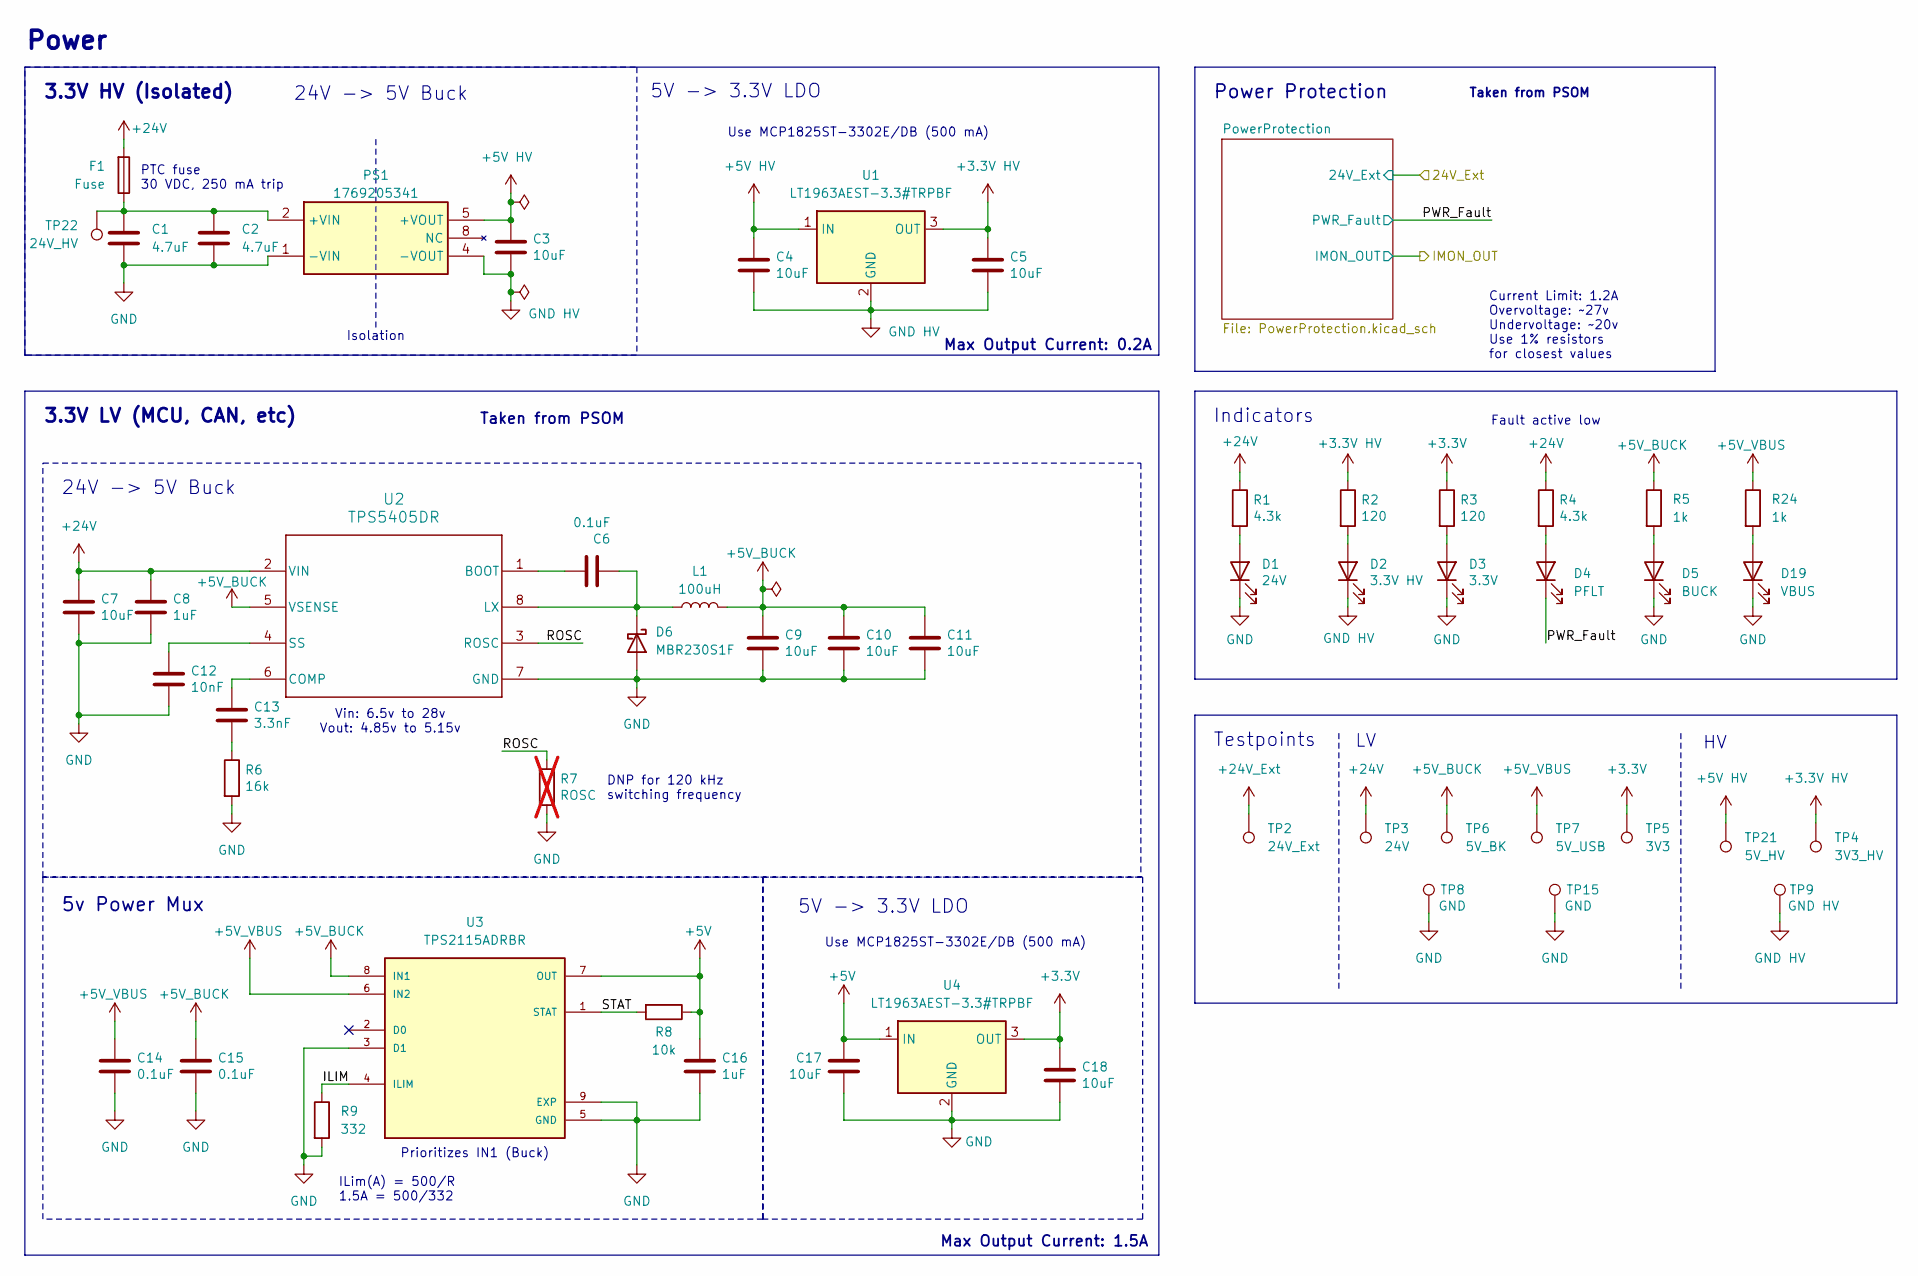
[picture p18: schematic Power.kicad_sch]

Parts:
C1, C2: 4.7uF; C_0805_2012Metric_Pad1.18x1.45mm_HandSolder
C3, C4, C5, C7, C9, C10, C11, C17, C18: 10uF; C_0805_2012Metric_Pad1.18x1.45mm_HandSolder
C6, C14, C15: 0.1uF; C_0603_1608Metric_Pad1.08x0.95mm_HandSolder
C8, C16: 1uF; C_0603_1608Metric_Pad1.08x0.95mm_HandSolder
C12: 10nF; C_0603_1608Metric_Pad1.08x0.95mm_HandSolder
C13: 3.3nF; C_0603_1608Metric_Pad1.08x0.95mm_HandSolder
D1: 24V; LED_0603_1608Metric_Pad1.05x0.95mm_HandSolder
D2: 3.3V HV; LED_0603_1608Metric_Pad1.05x0.95mm_HandSolder
D3: 3.3V; LED_0603_1608Metric_Pad1.05x0.95mm_HandSolder
D4: PFLT; LED_0603_1608Metric_Pad1.05x0.95mm_HandSolder
D5: BUCK; LED_0603_1608Metric_Pad1.05x0.95mm_HandSolder
D6: MBR230S1F; D_SOD-123F
D19: VBUS; LED_0603_1608Metric_Pad1.05x0.95mm_HandSolder
F1: Fuse; FUSC3216X125N
L1: 100uH; L_Coilcraft_MSS1246-XXX
PS1: 1769205341; WE_1769205341; Mouser Part Number 710-1769205341
R1, R4: 4.3k; R_0603_1608Metric_Pad0.98x0.95mm_HandSolder
R2, R3: 120; R_0603_1608Metric_Pad0.98x0.95mm_HandSolder
R5, R24: 1k; R_0603_1608Metric_Pad0.98x0.95mm_HandSolder
R6: 16k; R_0603_1608Metric_Pad0.98x0.95mm_HandSolder
R7: ROSC; R_0603_1608Metric_Pad0.98x0.95mm_HandSolder; not fitted
R8: 10k; R_0603_1608Metric_Pad0.98x0.95mm_HandSolder
R9: 332; R_0603_1608Metric_Pad0.98x0.95mm_HandSolder
TP2: 24V_Ext; TestPoint_Pad_1.0x1.0mm
TP3: 24V; TestPoint_Pad_1.0x1.0mm
TP4: 3V3_HV; TestPoint_Pad_1.0x1.0mm
TP5: 3V3; TestPoint_Pad_1.0x1.0mm
TP6: 5V_BK; TestPoint_Pad_1.0x1.0mm
TP7: 5V_USB; TestPoint_Pad_1.0x1.0mm
TP8, TP15: GND; PinHeader_1x01_P2.54mm_Vertical
TP9: GND HV; PinHeader_1x01_P2.54mm_Vertical
TP21: 5V_HV; TestPoint_Pad_1.0x1.0mm
TP22: 24V_HV; TestPoint_Pad_1.0x1.0mm
U1, U4: LT1963AEST-3.3#TRPBF; SOT-223-3_TabPin2
U2: TPS5405DR
U3: TPS2115ADRBR; VSON-8-1EP_3x3mm_P0.65mm_EP1.65x2.4mm

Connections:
+3.3V: C18.1, R3.1, TP5.1, U4.3 (OUT); also elsewhere on the board
+3.3V HV: C5.1, R2.1, TP4.1, U1.3 (OUT); also elsewhere on the board
+5V: C16.1, C17.1, R8.1, U3.7 (OUT), U4.1 (IN)
+5V HV: C3.1, C4.1, PS1.5 (+VOUT), TP21.1, U1.1 (IN)
+5V_BUCK: C9.1, C10.1, C11.1, C15.1, L1.2, R5.1, TP6.1, U2.5 (VSENSE), U3.8 (IN1)
+5V_VBUS: C14.1, R24.1, TP7.1, U3.6 (IN2); also elsewhere on the board
+24V: C7.1, C8.1, F1.2, R1.1, R4.1, TP3.1, U2.2 (VIN); also elsewhere on the board
+24V_Ext: TP2.1; also elsewhere on the board
/Power/ILIM: R9.1, U3.4 (ILIM)
/Power/PWR_Fault: D4.1 (K); also elsewhere on the board
/Power/ROSC: R7.1, U2.3 (ROSC)
/Power/STAT: R8.2, U3.1 (STAT)
GND: C1.2, C2.2, C7.2, C8.2, C9.2, C10.2, C11.2, C12.2, C14.2, C15.2, C16.2, C17.2, C18.2, D1.1 (K), D3.1 (K), D5.1 (K), D6.2 (A), D19.1 (K), PS1.1 (-VIN), R6.2, R7.2, R9.2, TP8.1, TP15.1, U2.7 (GND), U3.3 (D1), U3.5 (GND), U3.9 (EXP), U4.2 (GND); also elsewhere on the board
GND HV: C3.2, C4.2, C5.2, D2.1 (K), PS1.4 (-VOUT), TP9.1, U1.2 (GND); also elsewhere on the board
unnamed: C13.2, R6.1
unnamed: D1.2 (A), R1.2
unnamed: D2.2 (A), R2.2
unnamed: D3.2 (A), R3.2
unnamed: D4.2 (A), R4.2
unnamed: D5.2 (A), R5.2
unnamed: C6.2, D6.1 (K), L1.1, U2.8 (LX)
unnamed: D19.2 (A), R24.2
unnamed: C1.1, C2.1, F1.1, PS1.2 (+VIN), TP22.1
unnamed: C6.1, U2.1 (BOOT)
unnamed: C13.1, U2.6 (COMP)
unnamed: C12.1, U2.4 (SS)

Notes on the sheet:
Isolation
Max Output Current: 1.5A
Power
Testpoints
Use MCP1825ST-3302E/DB (500 mA)
Taken from PSOM
Indicators
Max Output Current: 0.2A
3.3V HV (Isolated)
Prioritizes IN1 (Buck)
5v Power Mux
Current Limit: 1.2A Overvoltage: ~27v Undervoltage: ~20v Use 1% resistors for closest values
5V -> 3.3V LDO
DNP for 120 kHz switching frequency
ILim(A) = 500/R 1.5A = 500/332
Vin: 6.5v to 28v Vout: 4.85v to 5.15v
24V -> 5V Buck
PTC fuse 30 VDC, 250 mA trip
3.3V LV (MCU, CAN, etc)
Power Protection
Fault active low

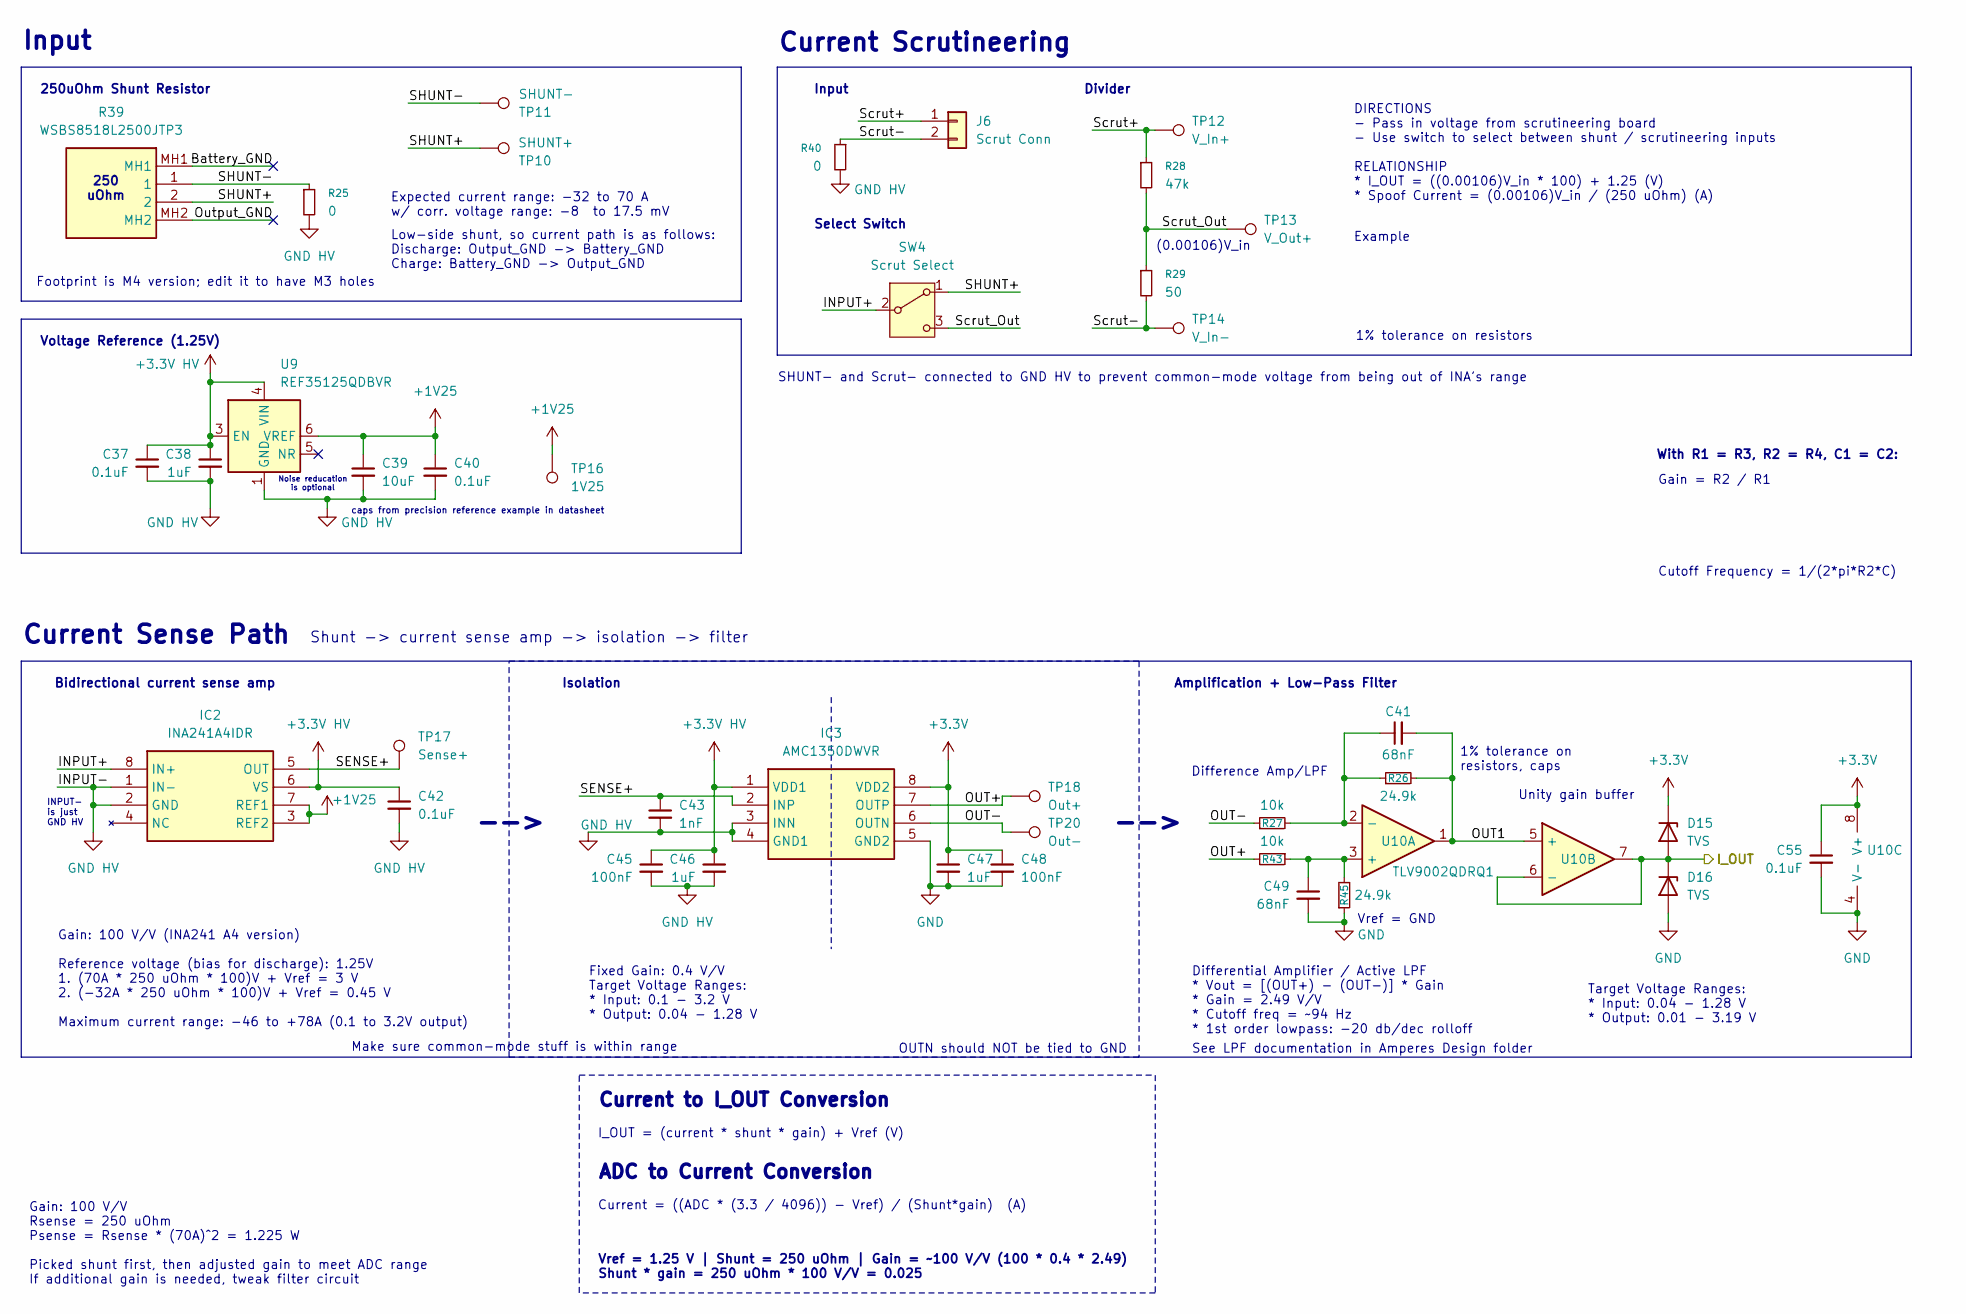
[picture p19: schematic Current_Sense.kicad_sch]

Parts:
C37, C40, C42, C55: 0.1uF; C_0603_1608Metric_Pad1.08x0.95mm_HandSolder
C38, C46, C47: 1uF; C_0603_1608Metric_Pad1.08x0.95mm_HandSolder
C39: 10uF; C_0805_2012Metric_Pad1.18x1.45mm_HandSolder
C41, C49: 68nF; C_0603_1608Metric_Pad1.08x0.95mm_HandSolder
C43: 1nF; C_0603_1608Metric_Pad1.08x0.95mm_HandSolder
C45, C48: 100nF; C_0603_1608Metric_Pad1.08x0.95mm_HandSolder
D15, D16: TVS; D_SOD-123F; Mouser Part Number 576-SMF3.3
IC2: INA241A4IDR; INA241A5IDR; Mouser Part Number 595-INA241A4IDR
IC3: AMC1350DWVR; Mouser Part Number 595-AMC1350DWVR
J6: Scrut Conn; Molex_Nano-Fit_105309-xx02_1x02_P2.50mm_Vertical
R25, R40: 0; R_0603_1608Metric_Pad0.98x0.95mm_HandSolder
R26, R45: 24.9k; R_0603_1608Metric_Pad0.98x0.95mm_HandSolder
R27, R43: 10k; R_0603_1608Metric_Pad0.98x0.95mm_HandSolder
R28: 47k; R_0603_1608Metric_Pad0.98x0.95mm_HandSolder
R29: 50; R_0603_1608Metric_Pad0.98x0.95mm_HandSolder
R39: WSBS8518L2500JTP3; WSBS8518L2500JKM4; Mouser Part Number 71-WSBS8518L2500JTP3
SW4: Scrut Select; SW_CJS-1200TA
TP10: SHUNT+; TestPoint_Pad_2.0x2.0mm
TP11: SHUNT-; TestPoint_Pad_1.0x1.0mm
TP12: V_In+; TestPoint_Pad_1.0x1.0mm
TP13: V_Out+; TestPoint_Pad_2.0x2.0mm
TP14: V_In-; TestPoint_Pad_1.0x1.0mm
TP16: 1V25; TestPoint_Pad_1.0x1.0mm
TP17: Sense+; TestPoint_Pad_1.0x1.0mm
TP18: Out+; TestPoint_Pad_1.0x1.0mm
TP20: Out-; TestPoint_Pad_1.0x1.0mm
U9: REF35125QDBVR; SOT-23-6
U10: TLV9002QDRQ1; SOIC-8_3.9x4.9mm_P1.27mm; Mouser P/N 595-TLV9002QDRQ1

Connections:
+1V25: C39.1, C40.1, IC2.3 (REF2), IC2.7 (REF1), TP16.1, U9.6 (VREF)
+3.3V: C47.1, C48.1, C55.1, D15.1 (K), IC3.8 (VDD2), U10.8 (V+); also elsewhere on the board
+3.3V HV: C37.1, C38.1, C42.1, C45.1, C46.1, IC2.6 (VS), IC3.1 (VDD1), U9.3 (EN), U9.4 (VIN); also elsewhere on the board
/Current Sense/Battery_GND: R39.MH1
/Current Sense/INPUT+: IC2.8 (IN+), SW4.2 (B)
/Current Sense/I_OUT: D15.2 (A), D16.1 (K), U10.6 (-), U10.7; also elsewhere on the board
/Current Sense/OUT1: C41.2, R26.2, U10.1, U10.5 (+)
/Current Sense/OUT+: IC3.7 (OUTP), R43.2, TP18.1
/Current Sense/OUT-: IC3.6 (OUTN), R27.1, TP20.1
/Current Sense/Output_GND: R39.MH2
/Current Sense/SENSE+: C43.1, IC2.5 (OUT), IC3.2 (INP), TP17.1
/Current Sense/SHUNT+: R39.2, SW4.1 (A), TP10.1
/Current Sense/SHUNT-: R25.1, R39.1, TP11.1
/Current Sense/Scrut+: J6.1, R28.1, TP12.1
/Current Sense/Scrut-: J6.2, R29.2, R40.1, TP14.1
/Current Sense/Scrut_Out: R28.2, R29.1, SW4.3 (C), TP13.1
GND: C47.2, C48.2, C49.2, C55.2, D16.2 (A), IC3.5 (GND2), R45.1, U10.4 (V-); also elsewhere on the board
GND HV: C37.2, C38.2, C39.2, C40.2, C42.2, C43.2, C45.2, C46.2, IC2.1 (IN-), IC2.2 (GND), IC3.3 (INN), IC3.4 (GND1), R25.2, R40.2, U9.1 (GND), U9.2 (GND); also elsewhere on the board
unnamed: C49.1, R43.1, R45.2, U10.3 (+)
unnamed: C41.1, R26.1, R27.2, U10.2 (-)

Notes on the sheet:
Gain: 100 V/V (INA241 A4 version) Reference voltage (bias for discharge): 1.25V 1. (70A * 250 uOhm * 100)V + Vref = 3 V 2. (-32A * 250 uOhm * 100)V + Vref = 0.45 V Maximum current range: -46 to +78A (0.1 to 3.2V output)
1% tolerance on resistors, caps
-->
Target Voltage Ranges: * Input: 0.04 - 1.28 V * Output: 0.01 - 3.19 V
(0.00106)V_in
Input
Unity gain buffer
Fixed Gain: 0.4 V/V Target Voltage Ranges: * Input: 0.1 - 3.2 V * Output: 0.04 - 1.28 V
Bidirectional current sense amp
Make sure common-mode stuff is within range
Current = ((ADC * (3.3 / 4096)) - Vref) / (Shunt*gain) (A)
Difference Amp/LPF
1% tolerance on resistors
Gain: 100 V/V Rsense = 250 uOhm Psense = Rsense * (70A)^2 = 1.225 W Picked shunt first, then adjusted gain to meet ADC range If additional gain is needed, tweak filter circuit
See LPF documentation in Amperes Design folder
Low-side shunt, so current path is as follows: Discharge: Output_GND -> Battery_GND Charge: Battery_GND -> Output_GND
ADC to Current Conversion
Current to I_OUT Conversion
With R1 = R3, R2 = R4, C1 = C2:
Isolation
Amplification + Low-Pass Filter
Vref = 1.25 V | Shunt = 250 uOhm | Gain = ~100 V/V (100 * 0.4 * 2.49) Shunt * gain = 250 uOhm * 100 V/V = 0.025
250 uOhm
Example
OUTN should NOT be tied to GND
DIRECTIONS - Pass in voltage from scrutineering board - Use switch to select between shunt / scrutineering inputs RELATIONSHIP * I_OUT = ((0.00106)V_in * 100) + 1.25 (V) * Spoof Current = (0.00106)V_in / (250 uOhm) (A)
Shunt -> current sense amp -> isolation -> filter
Differential Amplifier / Active LPF * Vout = [(OUT+) - (OUT-)] * Gain * Gain = 2.49 V/V * Cutoff freq = ~94 Hz * 1st order lowpass: -20 db/dec rolloff
Current Scrutineering
Select Switch
Divider
Cutoff Frequency = 1/(2*pi*R2*C)
Current Sense Path
Voltage Reference (1.25V)
INPUT- is just GND HV
250uOhm Shunt Resistor
Vref = GND
caps from precision reference example in datasheet
Expected current range: -32 to 70 A w/ corr. voltage range: -8 to 17.5 mV
I_OUT = (current * shunt * gain) + Vref (V)

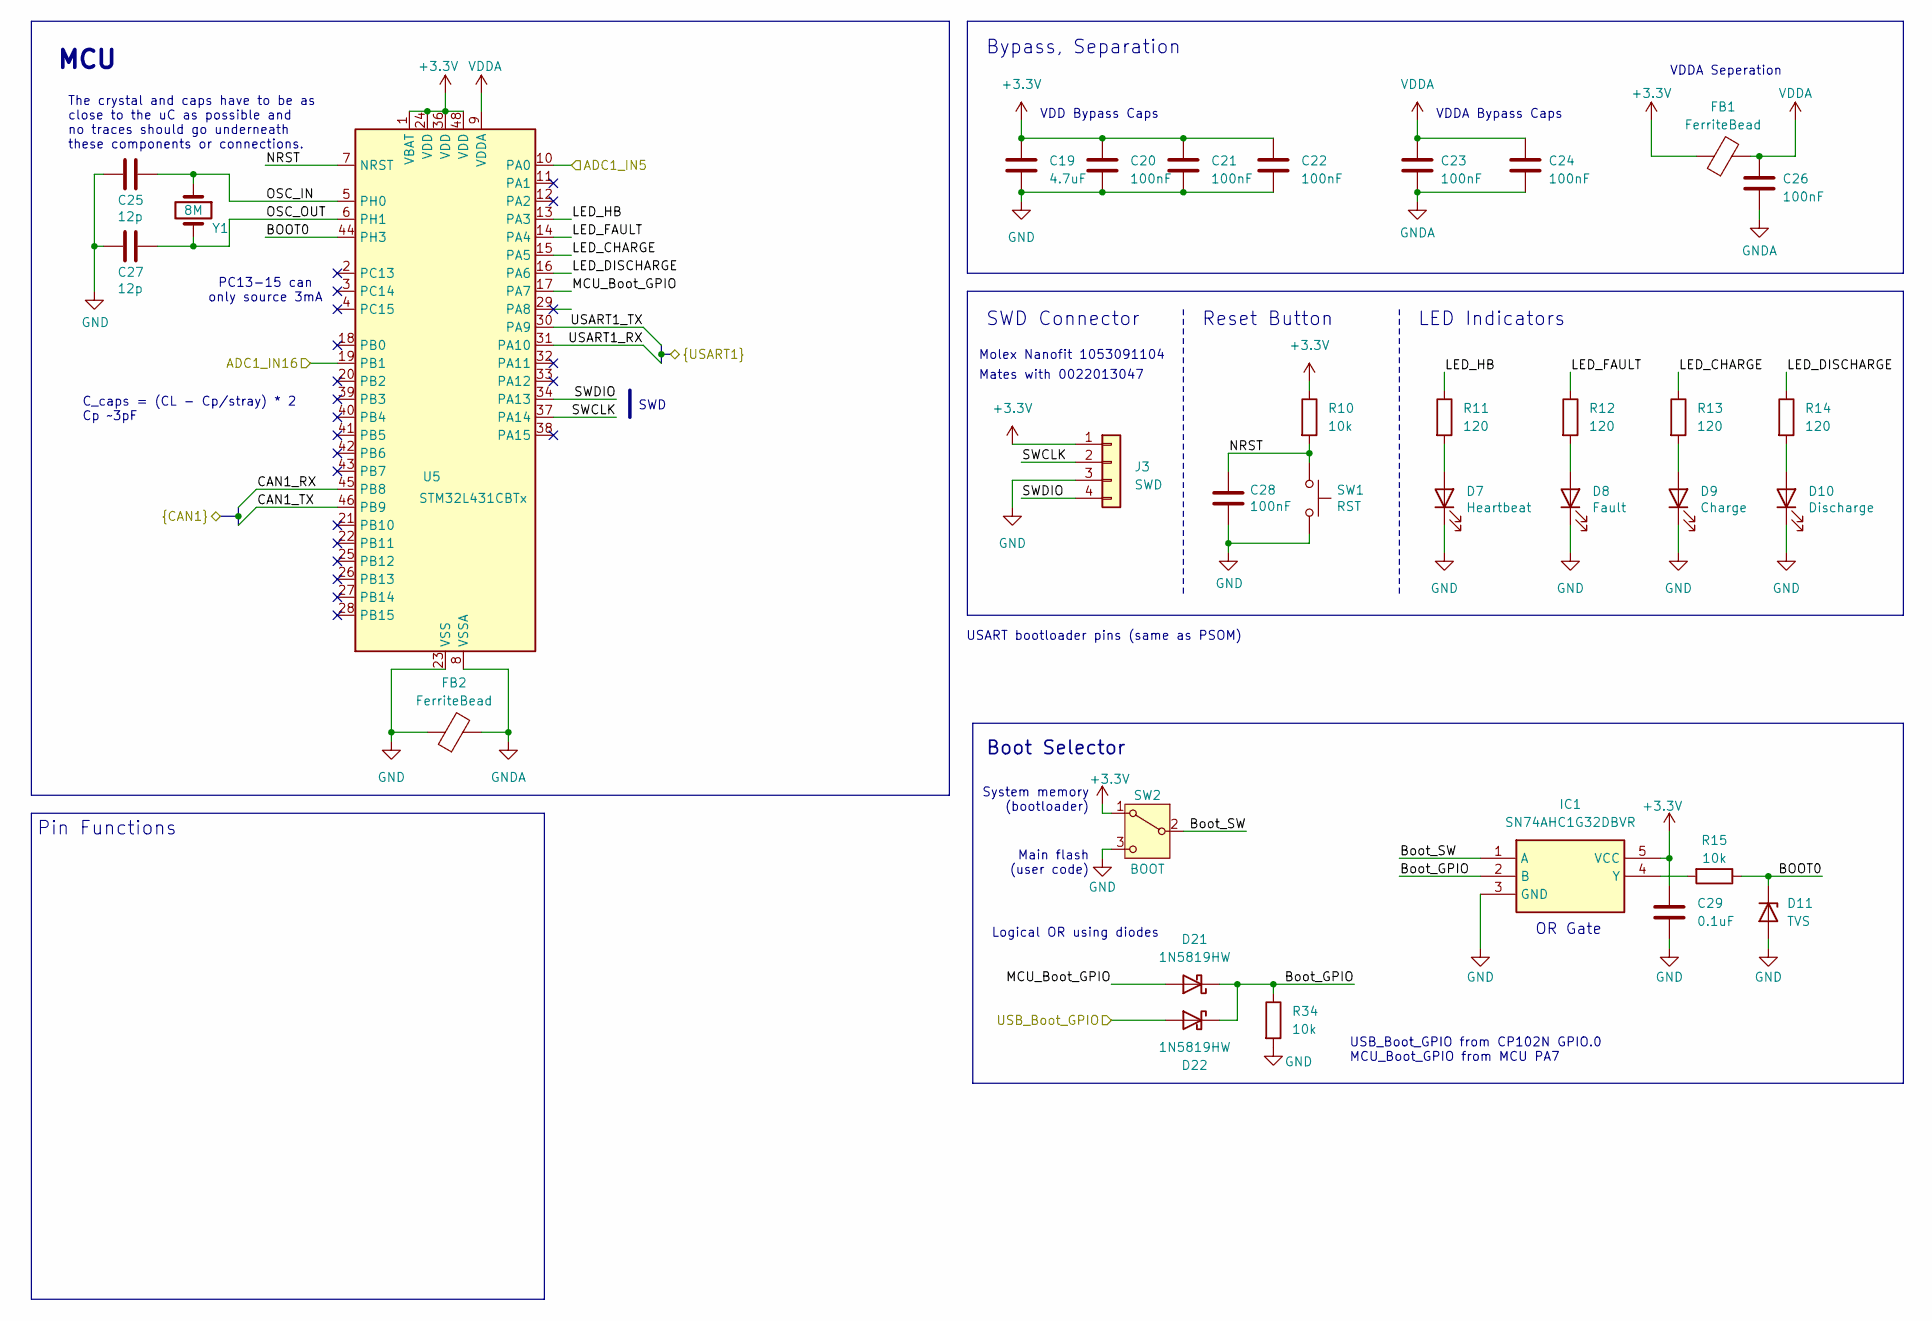
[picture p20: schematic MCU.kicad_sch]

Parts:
C19: 4.7uF; C_0805_2012Metric_Pad1.18x1.45mm_HandSolder
C20, C21, C22, C23, C24, C26, C28: 100nF; C_0603_1608Metric_Pad1.08x0.95mm_HandSolder; Mouser Part Number 80-C0805C104M5R
C25, C27: 12p; C_0603_1608Metric_Pad1.08x0.95mm_HandSolder; Mouser Part Number 80-C0805C120K5HACTU
C29: 0.1uF; C_0603_1608Metric_Pad1.08x0.95mm_HandSolder; Mouser Part Number 80-C0805C104M5R
D7: Heartbeat; LED_0603_1608Metric_Pad1.05x0.95mm_HandSolder
D8: Fault; LED_0603_1608Metric_Pad1.05x0.95mm_HandSolder
D9: Charge; LED_0603_1608Metric_Pad1.05x0.95mm_HandSolder
D10: Discharge; LED_0603_1608Metric_Pad1.05x0.95mm_HandSolder
D11: TVS; D_SOD-123F
D21, D22: 1N5819HW; D_SOD-123
FB1, FB2: FerriteBead; C_0603_1608Metric_Pad1.08x0.95mm_HandSolder; Mouser Part Number 704-MFBW1V2012-121-R
IC1: SN74AHC1G32DBVR; Mouser Part Number 595-SN74AHC1G32DBVR
J3: SWD; Molex_Nano-Fit_105309-xx04_1x04_P2.50mm_Vertical
R10: 10k; R_0603_1608Metric_Pad0.98x0.95mm_HandSolder; Mouser Part Number 71-CRCW080510K0FKEAC
R11, R12, R13, R14: 120; R_0603_1608Metric_Pad0.98x0.95mm_HandSolder
R15, R34: 10k; R_0603_1608Metric_Pad0.98x0.95mm_HandSolder
SW1: RST; SW_TL3365AF180QG
SW2: BOOT; SW_CJS-1200TA
U5: STM32L431CBTx; LQFP-48_7x7mm_P0.5mm; Mouser Part Number 511-STM32L431CBT6
Y1: 8M; Crystal_SMD_Abracon_ABM3-2Pin_5.0x3.2mm; Mouser Part Number 815-ABM3-8-D2Y-T

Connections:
+3.3V: C19.1, C20.1, C21.1, C22.1, C29.1, FB1.1, IC1.5 (VCC), J3.1, R10.1, SW2.1 (A), U5.1 (VBAT), U5.24 (VDD), U5.36 (VDD), U5.48 (VDD); also elsewhere on the board
/CAN/CAN1_RX: U5.45 (PB8); also elsewhere on the board
/CAN/CAN1_TX: U5.46 (PB9); also elsewhere on the board
/Current Sense/I_OUT: U5.10 (PA0); also elsewhere on the board
/MCU/ADC1_IN16: U5.19 (PB1); also elsewhere on the board
/MCU/BOOT0: D11.1 (K), R15.1, U5.44 (PH3)
/MCU/Boot_GPIO: D21.1 (K), D22.1 (K), IC1.2 (B), R34.1
/MCU/Boot_SW: IC1.1 (A), SW2.2 (B)
/MCU/LED_CHARGE: R13.1, U5.15 (PA5)
/MCU/LED_DISCHARGE: R14.1, U5.16 (PA6)
/MCU/LED_FAULT: R12.1, U5.14 (PA4)
/MCU/LED_HB: R11.1, U5.13 (PA3)
/MCU/MCU_Boot_GPIO: D21.2 (A), U5.17 (PA7)
/MCU/NRST: C28.1, R10.2, SW1.1, U5.7 (NRST)
/MCU/OSC_IN: C25.1, U5.5 (PH0), Y1.1
/MCU/OSC_OUT: C27.1, U5.6 (PH1), Y1.2
/MCU/SWCLK: J3.2, U5.37 (PA14)
/MCU/SWDIO: J3.4, U5.34 (PA13)
/MCU/USART1_RX: U5.31 (PA10); also elsewhere on the board
/MCU/USART1_TX: U5.30 (PA9); also elsewhere on the board
/MCU/USB_Boot_GPIO: D22.2 (A); also elsewhere on the board
GND: C19.2, C20.2, C21.2, C22.2, C25.2, C27.2, C28.2, C29.2, D7.1 (K), D8.1 (K), D9.1 (K), D10.1 (K), D11.2 (A), FB2.1, IC1.3 (GND), J3.3, R34.2, SW1.2, SW2.3 (C), U5.23 (VSS), U5.35 (VSS), U5.47 (VSS); also elsewhere on the board
GNDA: C23.2, C24.2, C26.2, FB2.2, U5.8 (VSSA)
unnamed: D7.2 (A), R11.2
unnamed: D8.2 (A), R12.2
unnamed: D9.2 (A), R13.2
unnamed: D10.2 (A), R14.2
unnamed: IC1.4 (Y), R15.2
VDDA: C23.1, C24.1, C26.1, FB1.2, U5.9 (VDDA)

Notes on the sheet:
SWD
Pin Functions
Logical OR using diodes
LED Indicators
Molex Nanofit 1053091104
PC13-15 can only source 3mA
MCU
Mates with 0022013047
The crystal and caps have to be as close to the uC as possible and no traces should go underneath these components or connections.
SWD Connector
C_caps = (CL - Cp/stray) * 2 Cp ~3pF
System memory (bootloader)
Reset Button
Boot Selector
USART bootloader pins (same as PSOM)
VDDA Bypass Caps
USB_Boot_GPIO from CP102N GPIO.0 MCU_Boot_GPIO from MCU PA7
VDD Bypass Caps
VDDA Seperation
OR Gate
Bypass, Separation
Main flash (user code)

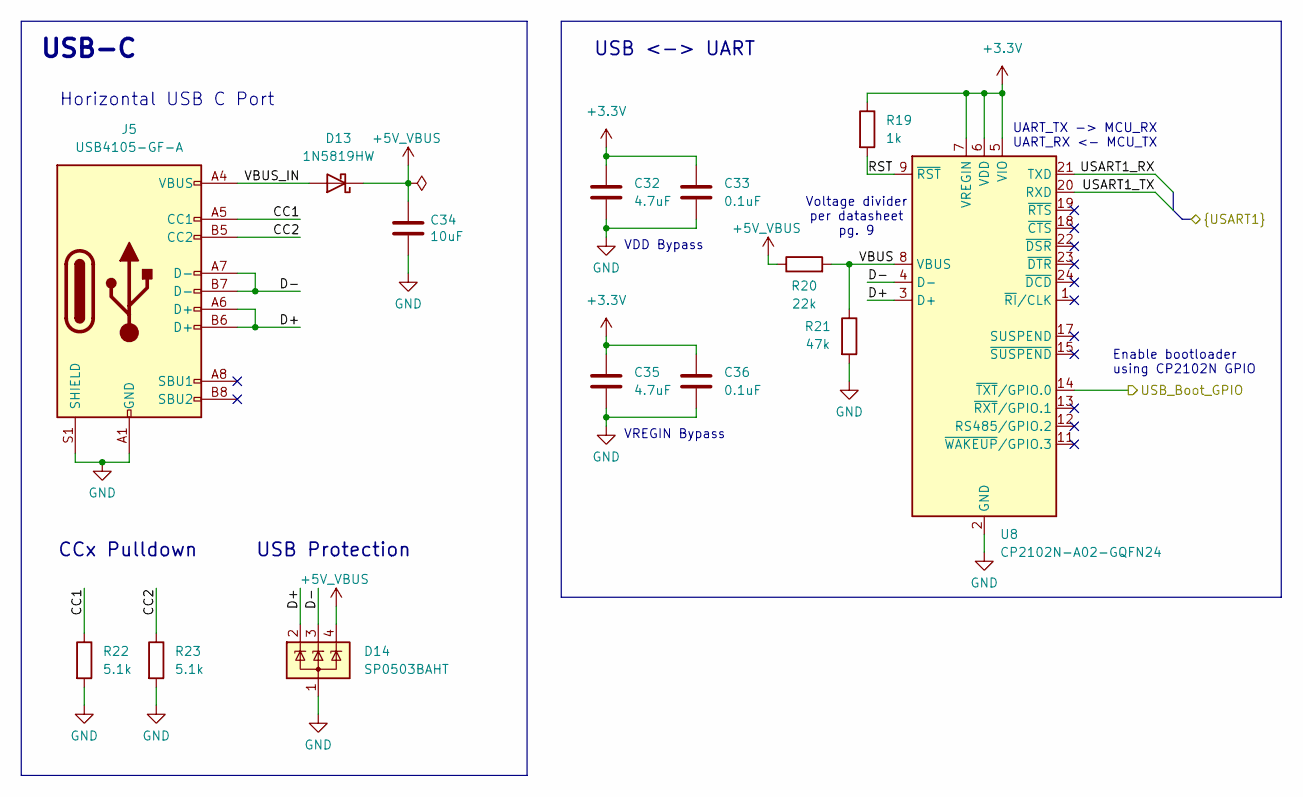
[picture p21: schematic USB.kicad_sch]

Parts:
C32, C35: 4.7uF; C_0805_2012Metric_Pad1.18x1.45mm_HandSolder
C33, C36: 0.1uF; C_0603_1608Metric_Pad1.08x0.95mm_HandSolder
C34: 10uF; C_0805_2012Metric_Pad1.18x1.45mm_HandSolder
D13: 1N5819HW; D_SOD-123
D14: SP0503BAHT; SOT-143; Mouser Part Number 576-SP0503BAHTG
J5: USB4105-GF-A; USB_C_Receptacle_GCT_USB4105-xx-A_16P_TopMnt_Horizontal
R19: 1k; R_0603_1608Metric_Pad0.98x0.95mm_HandSolder
R20: 22k; R_0603_1608Metric_Pad0.98x0.95mm_HandSolder
R21: 47k; R_0603_1608Metric_Pad0.98x0.95mm_HandSolder
R22, R23: 5.1k; R_0603_1608Metric_Pad0.98x0.95mm_HandSolder
U8: CP2102N-A02-GQFN24

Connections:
+3.3V: C32.1, C33.1, C35.1, C36.1, R19.1, U8.5 (VIO), U8.6 (VDD), U8.7 (VREGIN); also elsewhere on the board
+5V_VBUS: C34.1, D13.1 (K), D14.4 (K), R20.1; also elsewhere on the board
/MCU/USART1_RX: U8.21 (TXD); also elsewhere on the board
/MCU/USART1_TX: U8.20 (RXD); also elsewhere on the board
/MCU/USB_Boot_GPIO: U8.14 (~TXT/GPIO.0); also elsewhere on the board
/USB/CC1: J5.A5 (CC1), R22.1
/USB/CC2: J5.B5 (CC2), R23.1
/USB/D+: D14.2 (K), J5.A6 (D+), J5.B6 (D+), U8.3 (D+)
/USB/D-: D14.3 (K), J5.A7 (D-), J5.B7 (D-), U8.4 (D-)
/USB/RST: R19.2, U8.9 (~RST)
/USB/VBUS: R20.2, R21.1, U8.8 (VBUS)
/USB/VBUS_IN: D13.2 (A), J5.A4 (VBUS), J5.A9 (VBUS), J5.B4 (VBUS), J5.B9 (VBUS)
GND: C32.2, C33.2, C34.2, C35.2, C36.2, D14.1 (A), J5.A1 (GND), J5.A12 (GND), J5.B1 (GND), J5.B12 (GND), J5.S1 (SHIELD), R21.2, R22.2, R23.2, U8.2 (GND), U8.25 (GND); also elsewhere on the board

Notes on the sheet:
USB-C
USB <-> UART
Voltage divider per datasheet pg. 9
Horizontal USB C Port
Enable bootloader using CP2102N GPIO
VDD Bypass
CCx Pulldown
UART_TX -> MCU_RX UART_RX <- MCU_TX
VREGIN Bypass
USB Protection

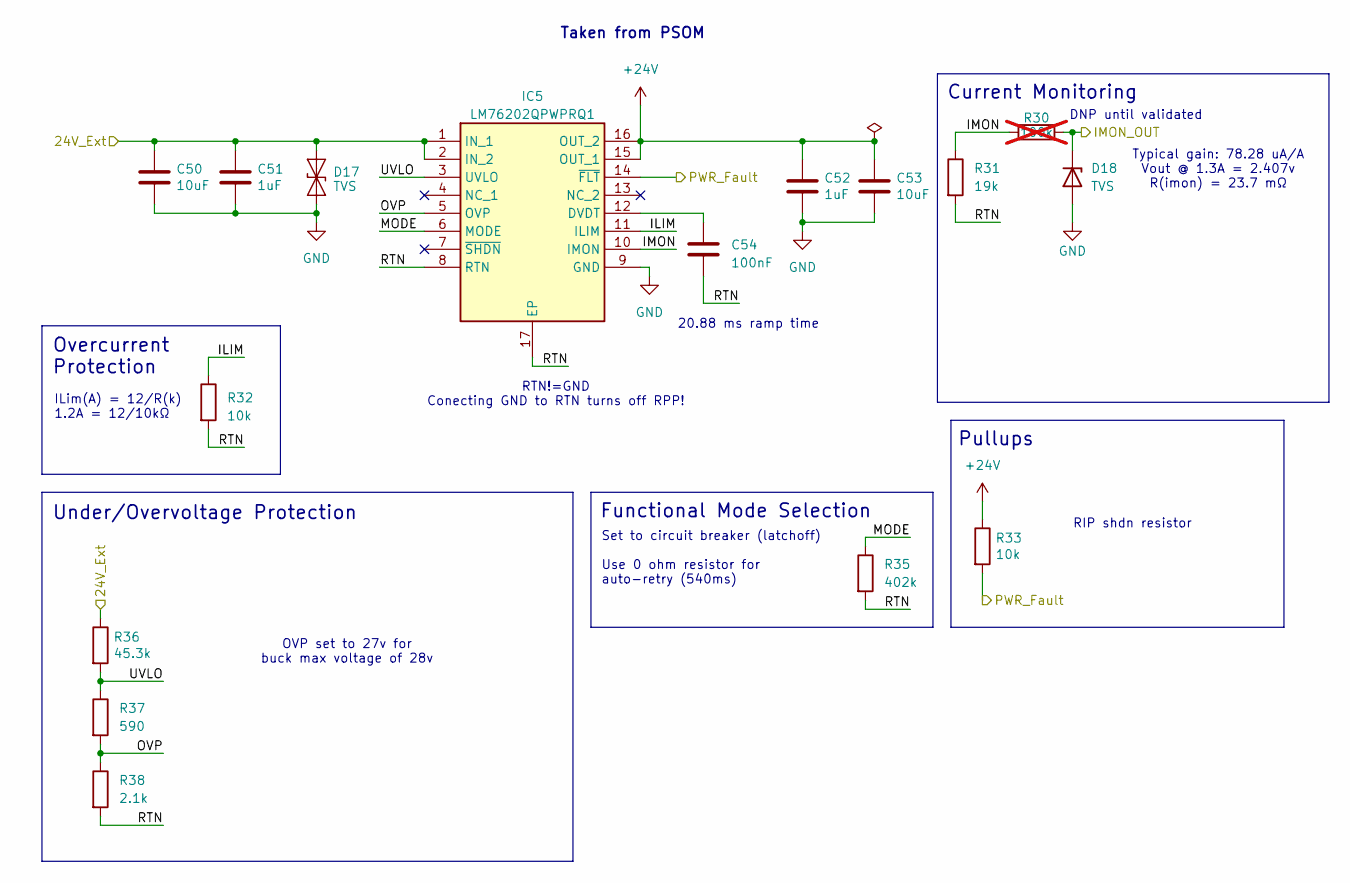
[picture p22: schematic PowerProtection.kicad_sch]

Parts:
C50, C53: 10uF; C_0805_2012Metric_Pad1.18x1.45mm_HandSolder
C51, C52: 1uF; C_0603_1608Metric_Pad1.08x0.95mm_HandSolder
C54: 100nF; C_0603_1608Metric_Pad1.08x0.95mm_HandSolder
D17: TVS; D_SOD-323_HandSoldering
D18: TVS; D_SOD-123F
IC5: LM76202QPWPRQ1; Mouser Part Number 595-LM76202QPWPRQ1
R30: 100k; R_0603_1608Metric_Pad0.98x0.95mm_HandSolder; not fitted
R31: 19k; R_0603_1608Metric_Pad0.98x0.95mm_HandSolder
R32, R33: 10k; R_0603_1608Metric_Pad0.98x0.95mm_HandSolder
R35: 402k; R_0603_1608Metric_Pad0.98x0.95mm_HandSolder
R36: 45.3k; R_0603_1608Metric_Pad0.98x0.95mm_HandSolder
R37: 590; R_0603_1608Metric_Pad0.98x0.95mm_HandSolder
R38: 2.1k; R_0603_1608Metric_Pad0.98x0.95mm_HandSolder

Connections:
+24V: C52.1, C53.1, IC5.15 (OUT_1), IC5.16 (OUT_2), R33.1; also elsewhere on the board
+24V_Ext: C50.1, C51.1, D17.2 (A2), IC5.1 (IN_1), IC5.2 (IN_2), R36.1; also elsewhere on the board
/MCU/ADC1_IN16: D18.1 (K), R30.2; also elsewhere on the board
/Power/PWR_Fault: IC5.14 (~FLT), R33.2; also elsewhere on the board
/Power/PowerProtection/ILIM: IC5.11 (ILIM), R32.1
/Power/PowerProtection/IMON: IC5.10 (IMON), R30.1, R31.1
/Power/PowerProtection/MODE: IC5.6 (MODE), R35.1
/Power/PowerProtection/OVP: IC5.5 (OVP), R37.2, R38.1
/Power/PowerProtection/RTN: C54.2, IC5.8 (RTN), IC5.17 (EP), R31.2, R32.2, R35.2, R38.2
/Power/PowerProtection/UVLO: IC5.3 (UVLO), R36.2, R37.1
GND: C50.2, C51.2, C52.2, C53.2, D17.1 (A1), D18.2 (A), IC5.9 (GND); also elsewhere on the board
unnamed: C54.1, IC5.12 (DVDT)

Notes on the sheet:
OVP set to 27v for buck max voltage of 28v
DNP until validated
RTN!=GND Conecting GND to RTN turns off RPP!
RIP shdn resistor
Under/Overvoltage Protection
Typical gain: 78.28 uA/A Vout @ 1.3A = 2.407v R(imon) = 23.7 mΩ
ILim(A) = 12/R(k) 1.2A = 12/10kΩ
20.88 ms ramp time
Set to circuit breaker (latchoff) Use 0 ohm resistor for auto-retry (540ms)
Pullups
Overcurrent Protection
Functional Mode Selection
Current Monitoring
Taken from PSOM

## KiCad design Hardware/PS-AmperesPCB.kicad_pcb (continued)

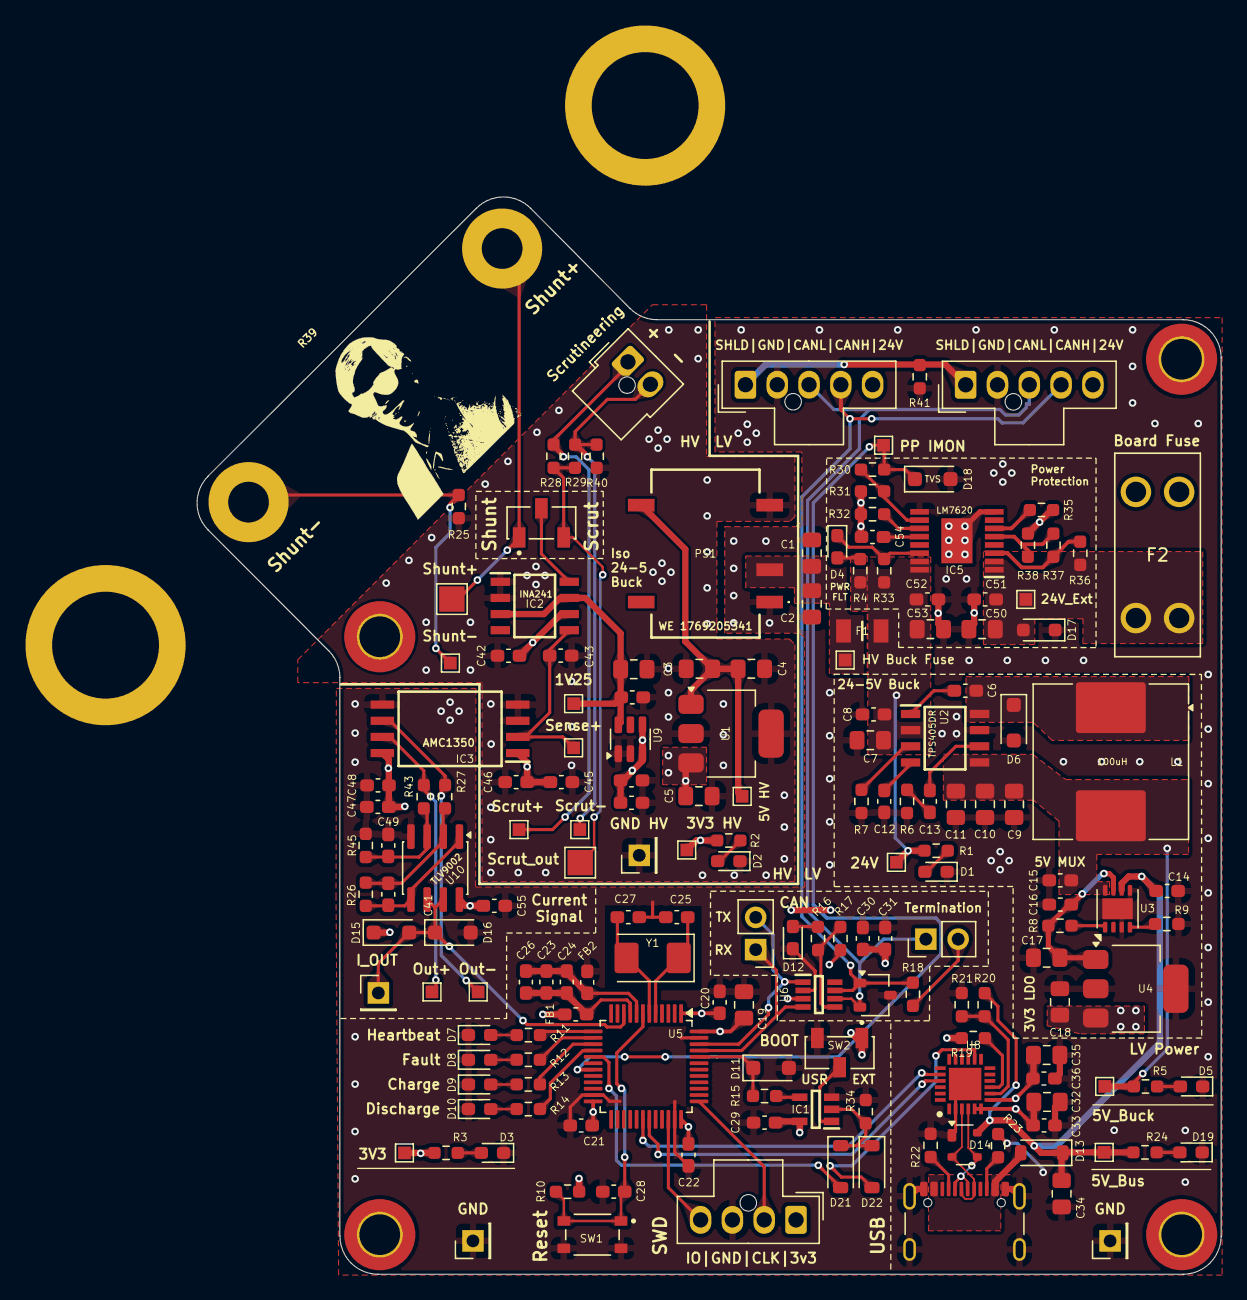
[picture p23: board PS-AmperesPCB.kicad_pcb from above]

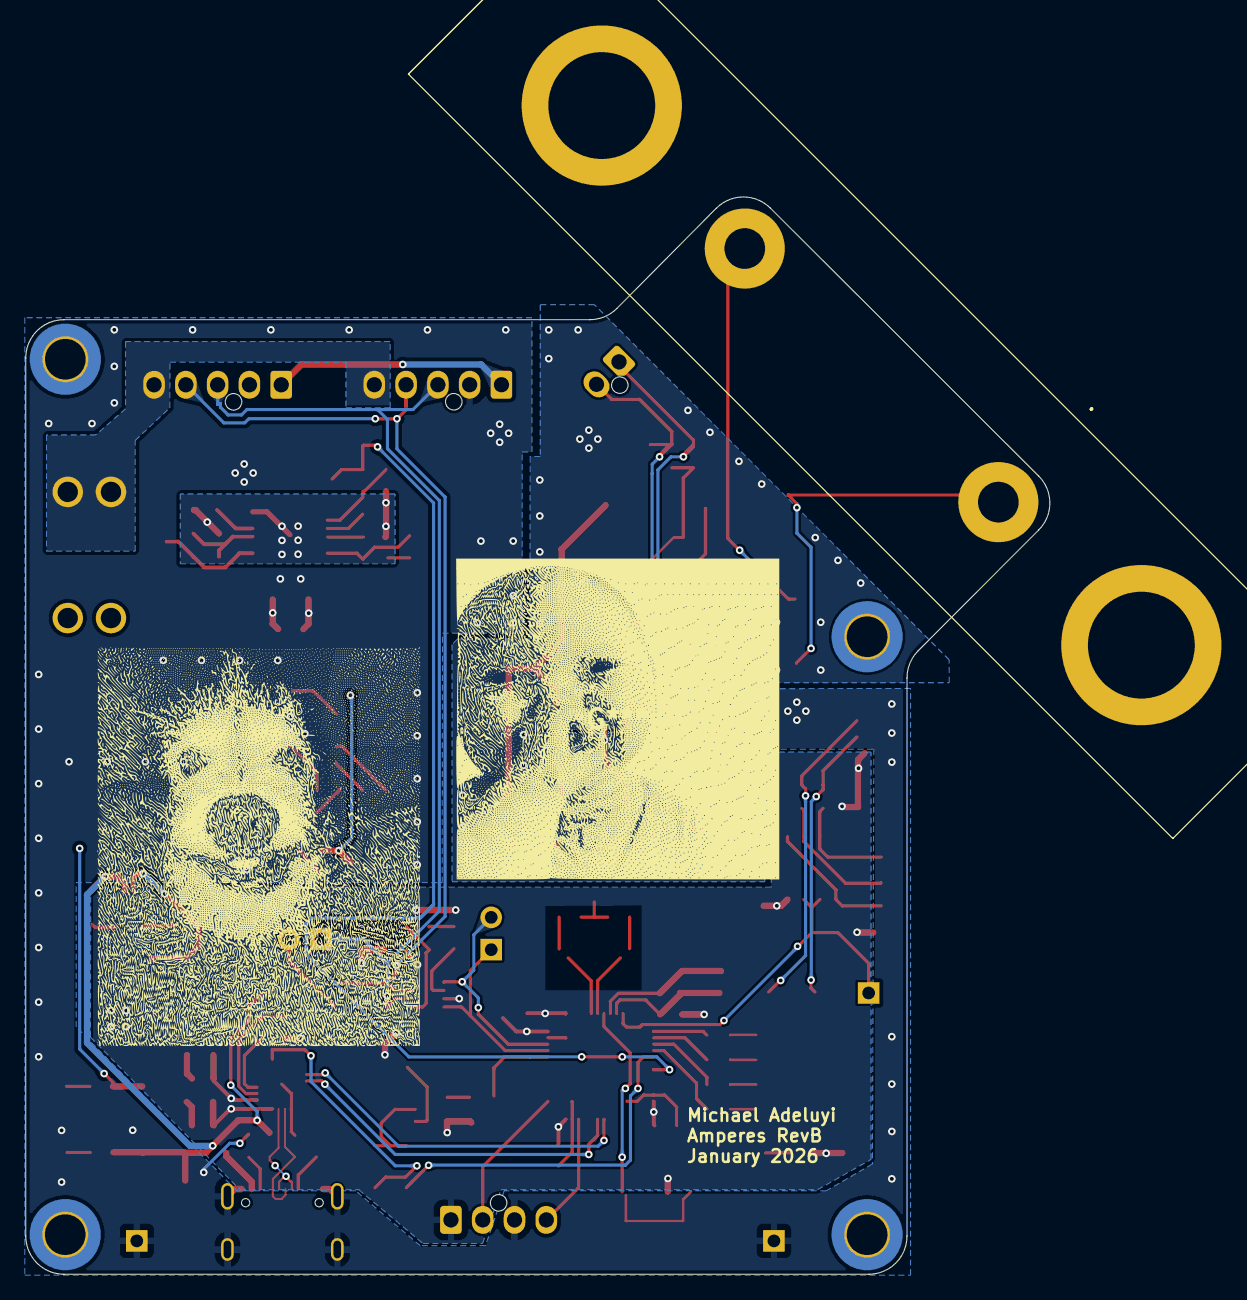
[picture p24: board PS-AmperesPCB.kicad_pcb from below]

Board: 2 copper layers, 80.5 x 84.7 mm, 177 parts (2 on the bottom side), 87 nets.

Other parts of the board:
C30, C31: 100nF; C_0603_1608Metric_Pad1.08x0.95mm_HandSolder
D12: CAN Status; LED_0603_1608Metric_Pad1.05x0.95mm_HandSolder
J4: Conn_01x02_Pin; PinHeader_1x02_P2.54mm_Vertical
JP1: Termination; PinHeader_1x02_P2.54mm_Vertical
R16, R18: 120; R_0603_1608Metric_Pad0.98x0.95mm_HandSolder
R17: 10k; R_0603_1608Metric_Pad0.98x0.95mm_HandSolder
U6: TCAN337; TCAN337DCNR
U7: CDSOT23-T24CAN

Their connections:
+3.3V: C30.1, C31.1, R17.2, U6.3 (VCC); also elsewhere on the board
/CAN/CAN1_RX: J4.1, U6.4 (RXD); also elsewhere on the board
/CAN/CAN1_TX: J4.2, U6.1 (TXD); also elsewhere on the board
/CAN/Fault: R16.1, R17.1, U6.5 (FAULT)
/CAN_HIGH: R18.2, U6.7 (CANH), U7.1 (CAN_H); also elsewhere on the board
/CAN_LOW: JP1.1 (A), U6.6 (CANL), U7.2 (CAN_L); also elsewhere on the board
GND: C30.2, C31.2, D12.1 (K), U6.2 (GND), U7.3 (GND); also elsewhere on the board
unnamed: D12.2 (A), R16.2
unnamed: JP1.2 (B), R18.1

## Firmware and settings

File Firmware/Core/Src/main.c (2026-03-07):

#include "stm32xx_hal.h"
#include "Tasks.h"


int main() {
    HAL_Init();
    SystemClock_Config();

    // Start Init Task
    xTaskCreateStatic(
        Task_Init,                  /* The function that implements the task. */
        "Task init",                /* Text name for the task. */
        TASK_INIT_STACK_SIZE,       /* The size (in words) of the stack that should be created for the task. */
        (void*)NULL,                /* Paramter passed into the task. */
        TASK_INIT_PRIO,             /* Task Prioriy. */
        Task_Init_Stack,            /* Stack array. */
        &Task_Init_Buffer           /* Buffer for static allocation. */
    );

    // Start scheduler
    vTaskStartScheduler();

    // Code should not reach here
    Error_Handler();
    while(1) {}
    
    return 0;
}

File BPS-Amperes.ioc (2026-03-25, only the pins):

Mcu.UserName=STM32L431CBTx
PA0.Signal=ADCx_IN5
PA10.Signal=USART1_RX
PA3.Signal=GPIO_Output
PA4.Signal=GPIO_Output
PA5.Signal=GPIO_Output
PA6.Signal=GPIO_Output
PA7.Signal=GPIO_Output
PA9.Signal=USART1_TX
PB8.Signal=CAN1_RX
PB9.Signal=CAN1_TX

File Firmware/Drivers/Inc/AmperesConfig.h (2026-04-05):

#pragma once

#include "stm32xx_hal.h"
#include "BPSCAN_can_msgs.h"

/** ================================================================
 *  Amperes Board
 *  ================================================================
 *  MCU: STM32L431CBT6
 *  ADC: PA0
 *  Operation: Receive data from ADC, convert to 
 *             current reading, and send over CAN.
 * 
 *  Specifications:
 *  - Current range: -46 to +78 A (0.1 - 3.2 V respectively)
 *  - Shunt: 250 uOhm
 *  - Gain: 100 * 0.4 * 2.49 V/V = 99.6 V/V
 *  - Reference voltage: 1.25 V (for bidirectional sense amp)
 *  - ADC: 12 bit
*/

/** ================================================================
 *  Status
 * ================================================================ */

typedef enum AmperesStatus {
    AMPERES_OK,
    AMPERES_ADC_INIT_FAIL,
    AMPERES_CAN_INIT_FAIL,
    AMPERES_CAN_START_FAIL,
    AMPERES_ADC_START_FAIL,
    AMPERES_ADC_READ_FAIL,
    AMPERES_CAN_SEND_FAIL
} AmperesStatus_t;

/** ================================================================
 *  GPIO
 * ================================================================ */

/* LED Pins */
#define AMPERES_GPIO_PORT       GPIOA
#define AMPERES_HB_PIN          GPIO_PIN_3
#define AMPERES_FAULT_PIN       GPIO_PIN_4
#define AMPERES_CHARGE_PIN      GPIO_PIN_5
#define AMPERES_DISCHARGE_PIN   GPIO_PIN_6

/* GPIO Pins */
#define AMPERES_BOOT_PIN        GPIO_PIN_7

/** ================================================================
 *  ADC (12 bit)
 * ================================================================ */

#define AMPERES_ADC_CHANNEL ADC_CHANNEL_5
#define AMPERES_SAMPLE_TIME ADC_SAMPLETIME_47CYCLES_5
#define AMPERES_ADC_PORT    GPIOA
#define AMPERES_ADC_PIN     GPIO_PIN_0

/** ================================================================
 *  CAN (CAN1)
 * ================================================================ */

#define AMPERES_MSG_DLC     CAN_DLC_BPS_PACK_CURRENT
#define AMPERES_MSG_ID      CAN_ID_BPS_PACK_CURRENT
#define AMPERES_CAN_PORT    GPIOB
#define AMPERES_RX_PIN      GPIO_PIN_8
#define AMPERES_TX_PIN      GPIO_PIN_9

/** ================================================================
 *  UART (USART1)
 * ================================================================ */

#define AMPERES_UART_PORT   GPIOA
#define AMPERES_UART_TX_PIN GPIO_PIN_9
#define AMPERES_UART_RX_PIN GPIO_PIN_10


#define AMPERES_INIT() do { \
    MX_GPIO_Init(); \
    if (Amperes_ADC_Init() != AMPERES_OK) { Error_Handler(); } \
    if (Amperes_CAN_Init() != AMPERES_OK) { Error_Handler(); } \
    if (Amperes_CAN_Start() != AMPERES_OK) { Error_Handler(); } \
    } while (0)

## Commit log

2025-12-19 added documentation for current range; added VBUS led
    [Current_Sense.kicad_sch, PS-AmperesPCB.kicad_sch, Power.kicad_sch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]
2025-12-19 INA common-mode fixed (i think)
    [Current_Sense.kicad_sch, PS-AmperesPCB.kicad_sch]
2025-12-19 differential amp for LPF
    [Current_Sense.kicad_sch, MCU.kicad_sch, USB.kicad_sch]
2025-12-20 diff amp / LPF
    [Current_Sense.kicad_sch, MCU.kicad_sch, PS-AmperesPCB.kicad_sch]
2025-12-20 some comments so I don't forget what I'm doing
    [Current_Sense.kicad_sch]
2025-12-23 new TLV symbol, SPDT switch for scrut
    [Current_Sense.kicad_sch, PS-AmperesPCB.kicad_sch, USB.kicad_sch]
2025-12-27 fixed LPF cutoff
    [Current_Sense.kicad_sch]
2025-12-27 refactored and added LPF docs; added fuse, boot_gpio from USB-UART chip
    [3568.step, AMC1350DWVR.stp, Current_Sense.kicad_sch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]
2025-12-27 i lowk haven't started layout
    [Current_Sense.kicad_sch]
2025-12-27 slightly cooked
    [Current_Sense.kicad_sch, MCU.kicad_sch, PS-AmperesPCB.kicad_pcb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]
2025-12-27 started layout not really but kind of
    [MCU.kicad_sch, PS-AmperesPCB.kicad_pcb]
2025-12-27 layout stuff
    [Current_Sense.kicad_sch, PS-AmperesPCB.kicad_pcb, PS-AmperesPCB.kicad_sch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]
2025-12-28 post review council sch changes: shielded connectors, removed SHDN resistor, diode OR for boot, standardized resistors
    [Current_Sense.kicad_sch, MCU.kicad_sch, PS-AmperesPCB.kicad_pcb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]
2025-12-29 starting routing i think
    [105309-1105.stp, 105309-1202.stp, Current_Sense.kicad_sch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]
2025-12-30 almost done with routing
    [1206L010_30WR.stp, PS-AmperesPCB.kicad_pcb, Power.kicad_sch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]
2025-12-31 drc is happy
    [PS-AmperesPCB.kicad_pcb]
2026-01-03 addressed some comments
    [PS-AmperesPCB.kicad_pcb, PS-AmperesPCB.kicad_sch, Power.kicad_sch]
2026-01-04 added lcsc part numbers
    [Current_Sense.kicad_sch, PS-AmperesPCB.kicad_pcb, PS-AmperesPCB.kicad_sch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]
2026-01-04 generated production files and docs
    [BOM-PS-AmperesPCB.csv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]
2026-01-04 updated STEP file
    [Current_Sense.kicad_sch, PS-AmperesPCB.step, board.step]
2026-01-07 symbol library
    [1769205341.stp, 3568.step, AMC1350DWVR.stp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]
2026-01-07 addressed comments; generated production files, docs
    [Current_Sense.kicad_sch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]
2026-01-12 added Mouser BOM, deleted embedded step files
    [105309-1105.stp, 105309-1202.stp, 1206L010_30WR.stp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]
2026-01-14 RevB Changes (#4)
    * added documentation for current range; added VBUS led
    * INA common-mode fixed (i think)
    * differential amp for LPF
    * diff amp / LPF
    * some comments so I don't forget what I'm doing
    * new TLV symbol, SPDT switch for scrut
    * fixed LPF cutoff
    * refactored and added LPF docs; added fuse, boot_gpio from USB-UART chip
    * i lowk haven't started layout
    * slightly cooked
    * started layout not really but kind of
    * layout stuff
    * post review council sch changes: shielded connectors, removed SHDN resistor, diode OR for boot, standardized resistors
    * starting routing i think
    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
    [AMC1350DWVR.stp, BOM-PS-AmperesPCB.csv, Current_Sense.kicad_sch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]
2026-03-07 Firmware Progress (#3)
    * added Embedded sharepoint
    * gitignore, added placeholder files to check compilation (it compiles hooray)
    * started outline for driver
    * first iteration of amperes code, testing init and get_reading using main
    * ADC init seems to work, CAN is set up (not tested)
    * finally back
    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
2026-03-25 Firmware Features (#5)
    * added c macros in makefile
    * can mirroring over uart works kinda maybe
    * formatting fix
    * can still works on peak;
    - can mirroring also works (printf readable at 10 Hz, gets funky at 100 Hz)
    - implemented tickless idle hook
    * printf instead of echo?
    * ☠️
    * bru
    * please
    * e
    * g
    * nix why
    * I can't spell
    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
    [AmperesADC.c, AmperesADC.h, Amperes_Task.c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]
2026-04-05 CAN Hotfix (#6)
    * pulled bps dbc, fixed amperes CAN msg send
    * send ADC in voltage instead of counts
    * oops
    * thanks gemini
    * reduced CAN send rate to 10Hz, addressed comment
    * fixed some stuff
    * memcpy
    * enabled bxcan AutoBusOff
    * pulled new printf stuff
    [AmperesADC.c, AmperesADC.h, AmperesConfig.h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]
2026-04-18 CAN Message Updates (#7)
    * sohan was here
    * double balls
    * fix build for all
    * fix truncation problems
    * updated amperes task (sends faults now) + can mirroring task
    * fixed unpacking for raw_mV msg
    * CAN msg unpacking function
    * fixed fault sending - alpenis was here
    ---------
    [AmperesADC.c, AmperesADC.h, Amperes_Task.c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]
2026-06-30 Update BPSCAN to ADC counts and send pack current at 25ms
    - Bump Embedded-Sharepoint submodule to main (rawv -> adc DBC change)
    - Regenerate BPSCAN_can_msgs.h; rename pack-current RawV -> ADC
    - Send raw 12-bit ADC counts instead of mV; rename send/unpack APIs
    - Send pack current every 25ms (was 100ms)
